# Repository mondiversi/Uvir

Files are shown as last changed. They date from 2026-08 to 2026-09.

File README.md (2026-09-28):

# Uvir

Android app for spectral irradiance acquisition and estimated biological effects.

## Status

Uvir is under active development. ESP32/AS7343 acquisition works over USB,
local Wi-Fi, Bluetooth and Internet through a standard MQTT broker over TLS. Optional AS7331
UVA/UVB/UVC acquisition is implemented in
energy-saving one-shot mode and awaits hardware validation and traceable
calibration when the UV board arrives.

## Android app

- Package: `me.mondiversi.uvir`
- Current version: `1.3.0` (sensor firmware `0.5.103`)
- Signed GitHub update checks at startup and from Info, verified APK downloads,
  and identity-checked USB sensor updates. The app is updated before the sensor.
  See [update and recovery documentation](docs/UPDATES.md).
- Multiple associated sensors can stay connected over Wi-Fi, Bluetooth or MQTT
  while one is selected for live display, settings and commands. Switching the
  selection keeps other sensors connected and continues saving their records.
  A single USB serial device can coexist with these wireless connections; USB
  hubs with multiple serial sensors are not yet supported. The no-sensor entry
  deliberately pauses all app connections without stopping hardware sessions.
- Spectral acquisitions, automatic acquisition, saved acquisitions, sharing and export, and estimated biological effects.
- Automatic acquisition can request unrestricted battery use and holds a partial wake lock while active, improving reliability when the screen is off. Force-closing the app can still stop the session.
- Firmware 0.5.95 makes the ESP32 the single authority for real-sensor
  averaging, automatic acquisitions and value alerts over USB, Wi-Fi and
  Bluetooth or Internet. While connected, completed automatic records are delivered from
  RAM and acknowledged by Android without routine flash writes. If the app
  connection drops, acquisitions, alerts and sensor errors are queued first in
  the sensor's 32 KiB FRAM, then on microSD when that queue fills,
  and synchronized after reconnection. Queued records are removed only after
  Android confirms that they are safely stored. Automatic-session and alert
  runtime state is checkpointed redundantly in FRAM, with the card as fallback.
  A DS3231 RTC on the
  shared I2C bus keeps UTC through a power loss, so valid sessions can resume
  autonomously without inventing records for the period in which the sensor
  was unpowered. The app corrects the RTC from the phone on every connection;
  invalid or uninitialized time still blocks every durable record.
- The in-app diagnostic performs six correlated probes and reports the complete
  hardware chain: processor and memory, AS7343/AS7331/DS3231/FRAM I²C state,
  FRAM and microSD read/write health, connection transports, LED and buzzer control
  paths, and the external-input GPIO. It does not create records or change
  settings and excludes every credential.
- Settings can be backed up from **Settings → Data and restore**: the app and
  each selected associated sensor produce separate password-encrypted
  `.uvirsettings` files. Multiple sensor backups can be imported together.
  A full database export is instead a password-protected AES-256 ZIP containing
  the SQLite database; it can be opened on a computer with a compatible ZIP
  program. The app can import that encrypted ZIP after checking the password,
  database integrity and schema version. Import replaces the local records and
  sensor profiles atomically; it does not change the physical sensor.
- Before an app authenticates, Internet, Bluetooth and local Wi-Fi now take
  part in the same 20-second recovery cycle. An invalid Internet broker or
  network therefore cannot leave the sensor permanently unreachable. Internet
  authentication also expires when the app stops communicating, so closing
  Android resumes the same recovery cycle even while the broker socket itself
  remains alive.
- Averaged automatic acquisitions are collected incrementally, so the ESP32
  continues to process connection, stop and diagnostic commands between raw
  samples instead of blocking for the complete averaging interval.
- Sensor parameters now group the RGB connection/activity LED, the separate
  blue pending-synchronization LED and an optional passive piezo buzzer. The
  buzzer uses GPIO 32,
  defaults to 10% volume, and confirms app connection, disconnection, activity
  start or stop, and every saved acquisition or alert without blocking sampling.

## Project structure

- `app/`: Android application.
- `firmware/esp32/UvirSensor/`: ESP32 firmware with separate AS7343 and optional AS7331 drivers plus the versioned Uvir USB/Wi-Fi/Bluetooth protocol.
- `relay/`: legacy experimental Uvir relay retained for reference; current Internet mode uses standard MQTT/TLS.
- `hardware/`: breadboard wiring, pinouts, schematics, bill of materials, and hardware test notes.

Third-party computers, phones and embedded USB hosts can control the sensor
without the Android app. See [USB serial integration](docs/USB_SERIAL_PROTOCOL.md)
for connection settings, commands, JSON responses, record acknowledgements and
safe offline synchronization.

## Remote Internet connection

Internet mode uses a standard MQTT 3.1.1 broker protected by TLS. Both the app
and the ESP32 establish outgoing connections, so no port needs to be opened on
the sensor's router. The broker address, TLS port and MQTT credentials are user
configuration: Uvir does not hard-code or depend on a particular provider.
Commands from the app use QoS 1; sensor events use non-blocking QoS 0, and
retained messages are disabled. Durable offline records remain protected by
Uvir's explicit `SYNC_ACK` and replay protocol. Uvir's sensor-specific
authentication remains active inside the encrypted MQTT channel.

See [ARCHITECTURE.md](ARCHITECTURE.md) for the current module boundaries and
the rules used for gradual, low-risk refactoring.

## First sensor test

Open `firmware/esp32/UvirSensor/UvirSensor.ino` in Arduino IDE, select
**ESP32 Dev Module**, choose **Huge APP (3MB No OTA/1MB SPIFFS)** under
**Tools → Partition Scheme**, and upload it to the ESP32. The Android app
recognizes the current CP210x USB serial bridge and asks for USB access when the
sensor is connected to the phone through a USB OTG data cable.

Disable **Settings → Debug → Mock data** before testing the real sensor. AS7343
VIS/NIR and optional AS7331 UV values remain datasheet-based estimates until
the assembled instrument is calibrated against a traceable reference.

## License

Licensed under the GNU General Public License v3.0. See [LICENSE](LICENSE).

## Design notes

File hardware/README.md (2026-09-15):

# Hardware

This directory is reserved for the physical design and assembly documentation
used by Uvir.

Planned contents:

- breadboard wiring diagrams;
- pin assignments and I2C addresses;
- power requirements and level-shifting notes;
- schematics and PCB revisions;
- bill of materials;
- assembly photos and sensor test notes.

The first carrier-board engineering draft is in
`pcb/uvir-carrier-r0`. It contains the verified logical schematic, preliminary
placement, BOM and fabrication profile. Gerbers remain intentionally blocked
until the exact physical modules have been measured.

Firmware source code belongs in `firmware/esp32/UvirSensor`. Keeping hardware
documents separate from firmware makes the repository easier to navigate as
the prototype evolves beyond a breadboard.

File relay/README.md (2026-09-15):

# Uvir Internet relay

The relay lets the Android app and an ESP32 sensor meet through the Internet
without exposing the sensor or opening a port on the home router. Both sides
create an outbound TLS connection and are paired using the sensor identity and
a key derived from its private access token. The normal authenticated Uvir
protocol then passes through unchanged.

## Requirements

- A small public server with a DNS name.
- A TLS certificate whose chain is rooted at Let's Encrypt ISRG Root X1.
- Node.js 20 or later. There are no third-party packages.

Set `UVIR_TLS_CERT` and `UVIR_TLS_KEY` to the full certificate-chain and private
key paths. Set `UVIR_RELAY_PORT` if the service does not listen on `443`, then
run `node uvir-relay.mjs`. Allow that inbound TCP port on the relay server only.
No port must be opened on the sensor's router.

The relay intentionally stores no measurements and logs no channel keys. It
only forwards bytes while both authenticated endpoints are online. Production
deployment should run it under a restricted service account, add connection
rate limits at the firewall, and restart it automatically after failure.

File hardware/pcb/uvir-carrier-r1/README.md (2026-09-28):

# Uvir Carrier R1 — EasyEDA Standard

## File to open in EasyEDA

`uvir-carrier-r1-easyeda-standard-schematic.json` is a **native EasyEDA Standard
electrical schematic**. The first version loaded the components but used only
short wire stubs with net names, so they appeared disconnected. This version
uses continuous wires and explicit junctions. It contains 13 symbols, 52 pins,
17 nets and 69 segments. The generator checks that every net is electrically
continuous in the drawing, rather than merely sharing a label.
The new version has not yet been reimported and visually checked in the EasyEDA
editor.

In EasyEDA **Standard** for PC:

1. Open `File > Open > EasyEDA...`.
2. Select `uvir-carrier-r1-easyeda-standard-schematic.json`.
3. Leave **Import File** selected and confirm.

Do not open the file by double-clicking it in Windows or choose Altium, Eagle
or KiCad. `uvir-carrier-r1-pin-netlist.json` is the reference logical pin map,
**not** a native EasyEDA document.

## Pin mapping and placement

The ESP32 symbol shows the `J2` (left row) and `J3` (right row) positions when
viewing the front of the board with USB at the bottom. These follow the
user-supplied `esp32_pin_ref.jpg` reference photo and agree with the 38-pin
ESP32-DevKitC pinout. The actual row spacing and pin pitch must still be measured
on the board before designing the sockets.

The **electrical schematic** arranges blocks to make the wiring readable; it
does not represent the physical PCB layout. Intended placement is recorded in
the logical pin map's `layout` section:

- **Front, bottom to top:** ESP32 with USB facing the bottom edge; horizontal
  AS7343 visible/NIR board above it; horizontal UV 5 Click board further up;
  buzzer, RGB LED and blue LED at the top. Side button on the left, slightly
  above the midpoint.
- **Back, bottom to top:** transverse RTC; clear ESP32 antenna area; FRAM above;
  microSD adapter at the top with the card accessible from the edge.
- **Approximate dimensions:** ESP32 25×52 mm; AS7343 22×13 mm;
  UV 5 Click 28.6×25.4 mm; RTC 37×22 mm; FRAM 20×15 mm;
  microSD 24×43 mm. These are not sufficient for fabrication.

The four I²C peripherals share GPIO21/SDA, GPIO22/SCL, 3.3 V and GND.
The microSD module uses GPIO13/18/19/23 for SPI, and only its VCC uses 5 V,
following the previously tested adapter with a regulator and level shifting.
Each LED has its own 330 Ω series resistor. Pressing the external button pulls
GPIO33 to GND: the chosen terminals are on opposite sides of the contact.

## Requirements before ordering the PCB

This document defines the connections; it is **not** a PCB layout. The module
symbols do not yet have physical footprints assigned. Before generating Gerbers:

- Measure pin 1, pin order, pitch and socket row spacing for every module,
  as well as LED/buzzer polarity and microSD orientation.
- Create/assign the footprints and place them on the actual front/back layout.
- Check the 3.3 V regulator budget, existing module I²C pull-ups, optical
  isolation and the antenna copper keepout.
- Check that RTC charging is disabled when using a CR2032.
- Run ERC, DRC and a human review before ordering.

`generate_easyeda_standard.py` regenerates the file from the logical pinout and
stops if a pin is missing or duplicated, a net is discontinuous, or the GPIO map
does not match `UvirHardwareConfig.h`.
The actual generator is `generate_connected_easyeda.py`; the original name
remains available for compatibility.

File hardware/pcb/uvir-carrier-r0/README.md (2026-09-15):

# Uvir Carrier PCB R0

Status: **engineering draft — not ready to order**.

This package fixes the electrical architecture and the intended physical
arrangement of the first Uvir carrier board. It deliberately does not contain
Gerber or drill production files yet: the exact physical ESP32 and GY-AS7343
module dimensions have not been verified. A correct logical pinout is not a
substitute for a mechanical footprint.

## Intended arrangement

From the USB edge toward the top edge:

1. ESP32 38-pin development board, USB connector accessible through the lower
   enclosure opening;
2. antenna keep-out, with no copper, ground plane, traces or components below
   the ESP32 antenna;
3. GY-AS7343 visible/NIR sensor, mounted horizontally and facing the front
   optical window;
4. SparkFun AS7331 UV sensor, mounted horizontally and facing its own front
   optical window;
5. opaque optical divider;
6. blue LED, common-cathode RGB LED and passive buzzer at the top edge. The LEDs
   use right-angle packages or light pipes so their output exits from the top
   face rather than shining toward the sensors. The buzzer may remain flat and
   use an acoustic duct to the top face.

Provisional carrier outline: **40 x 125 mm**, two copper layers, 1.6 mm FR-4.
This size is only a placement target and must be recalculated from the verified
footprints.

## Authoritative logical connections

- I2C SDA: GPIO 21;
- I2C SCL: GPIO 22;
- AS7343 address: `0x39`;
- AS7331 address: `0x74`;
- RGB red: GPIO 25 through 330 ohm;
- RGB green: GPIO 26 through 330 ohm;
- operation LED blue: GPIO 27 through 330 ohm;
- passive piezo buzzer: GPIO 32 and GND;
- sensor supply: 3.3 V after verification that each breakout contains the
  required regulator/level shifting.

## Files

- `uvir-carrier-r0-schematic.svg`: readable electrical schematic;
- `uvir-carrier-r0-layout.svg`: dimensioned placement drawing;
- `uvir-carrier-r0-pin-map.csv`: connector/net mapping;
- `uvir-carrier-r0-bom.csv`: preliminary bill of materials;
- `uvir-carrier-r0-cpl.csv`: preliminary placement list;
- `uvir-carrier-r0-board-outline.dxf`: provisional 40 x 125 mm outline;
- `fabrication-settings.md`: recommended fabrication settings and the exact
  checks required before Gerber generation.

## Measurements still required

Measure the physical parts with a caliper and record:

- ESP32 board width and length;
- center-to-center distance between its two 19-pin rows;
- location of pin 1, first/last pin and USB overhang;
- GY-AS7343 board width/length and exact order/position of its six pins;
- confirmation that the AS7331 is SEN-23517 Standard (25.4 x 25.4 mm), not the
  25.4 x 12.7 mm Mini version;
- buzzer diameter, height and lead spacing;
- LED package diameter and lead spacing;
- desired enclosure wall thickness and mounting-hole positions.

Only after these values are checked should the order bundle be generated:
Gerber X2/RS-274X, Excellon drill, BOM and component-position CSV. Those formats
are accepted by the main PCB fabrication services without tying the design to a
single provider.

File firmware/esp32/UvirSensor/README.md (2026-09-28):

# Uvir ESP32 sensor firmware

This sketch is the first hardware bridge between Uvir for Android and an
ESP32 Dev Module fitted with a GY-AS7343 spectral sensor and, optionally, an
AS7331 UV sensor. It streams visible, far-red, NIR, UVA, UVB and UVC bands over
USB serial, the local Wi-Fi network, Bluetooth Classic SPP, or an encrypted
Internet relay. Firmware keeps
working with UV values unavailable when the optional AS7331 is not installed.

## Settings authority and interrupted transfers

Firmware 0.5.102 reports `settings_updated_at_ms` in `HELLO`: UTC Unix
milliseconds of the last committed configuration change, persisted in NVS.
Receiving `TIME`, connecting, reading samples and running sessions do not refresh
this revision. Native serial configuration edits also advance it monotonically,
even if the runtime clock is unavailable or moves backwards.

Android keeps a separate revision/outbox for each hardware identity. Hardware
wins when its revision is equal or newer; otherwise Android resends its pending
configuration after authentication. Writes are queued durably before transfer
and are not acknowledged merely because a socket write succeeded. Pending
commands containing network credentials are excluded from Android cloud/device
backups; explicit encrypted settings exports include the desired settings.

`SETTINGS_APPLY <updated_at_ms> <hex_utf8_commands>` applies a bounded batch of
configuration commands separated by newlines. Its revision is committed only
after all commands succeed. Older/equal batches are ignored and answered with
`HELLO`. Interrupted/partially applied batches keep the previous revision and
can be retried. Radio reconnection is deferred until after commit/readback.
This is a recoverable configuration batch, not an atomic flash transaction.
The allowlist excludes acquisition, reset, session start/stop and other
operational commands. `ALERT_SETTINGS` synchronizes alert rules/timing without
changing an active session's identity, counters, cooldown or enabled state.

The outbox is invalidated when the association's access token changes (factory
reset), when that sensor is disassociated, or when the app's associations are
reset. Older firmware retains its previous sensor-authoritative readback behavior.

## Current wiring

| GY-AS7343 | ESP32 Dev Module |
|---|---|
| SDA | GPIO 21 |
| SCL | GPIO 22 |
| GND | GND |
| VIN/VCC | See the voltage warning below |
| I / INT | Not connected; optional active-low interrupt output |
| G / GPIO | Not connected; optional trigger/synchronization GPIO |

Optional SparkFun AS7331 / SEN-23517 on the same I2C bus:

| AS7331 | ESP32 Dev Module |
|---|---|
| SDA | GPIO 21 (shared with AS7343) |
| SCL | GPIO 22 (shared with AS7343) |
| GND | GND |
| 3V3 | 3.3 V |
| INT | Not connected |
| SYN | Not connected |

The sensors do not conflict: AS7343 uses address `0x39` and AS7331 uses
`0x74`. The AS7331 runs in command/one-shot mode and therefore does not need
its `INT` or `SYN` pins for Uvir.

HW-084 / DS3231 battery-backed real-time clock on the same I2C bus:

| RTC module | ESP32 Dev Module |
|---|---|
| SDA | GPIO 21 (shared I2C bus) |
| SCL | GPIO 22 (shared I2C bus) |
| VCC | 3.3 V |
| GND | GND |
| SQW / 32K | Not connected |

The DS3231 uses address `0x68`; the module's optional AT24C32 EEPROM commonly
uses `0x57` and is not used by Uvir. The backup cell powers only the clock when
main power is absent, so the module power LED going out is normal. If a CR2032
is fitted, the module's charging path must remain disabled. Uvir stores UTC in
the RTC and converts it for display in Android.

32 KiB MB85RC256V I²C FRAM on the shared bus:

| FRAM module | ESP32 Dev Module |
|---|---|
| SDA | GPIO 21 |
| SCL | GPIO 22 |
| VCC | 3.3 V |
| GND | GND |
| WP / A0 / A1 / A2 | Leave at the module defaults; do not drive high |

The tested board answers at `0x50`, independently of AS7343 (`0x39`), DS3231
(`0x68`) and optional AS7331 (`0x74`). FRAM keeps two checksummed copies of
the current activity state and up to 92 pending final records. Each record is
committed after a readback, then removed only after Android acknowledges it.
The remaining 4 KiB are reserved for future diagnostics. If FRAM is absent or
belongs to a different sensor, the microSD/LittleFS path remains available;
foreign FRAM contents are never silently erased.

Generic 6-pin microSD adapter with onboard level conversion (durable overflow
storage):

| microSD adapter | ESP32 Dev Module |
|---|---|
| CS | GPIO 13 |
| SCK | GPIO 18 |
| MOSI | GPIO 23 |
| MISO | GPIO 19 |
| VCC | 5 V / VIN |
| GND | GND |

The tested generic board uses an SN74HC125 level-conversion buffer and a 3.3 V
regulator, so its `VCC` input is powered from 5 V while all SPI signals remain
safe for the ESP32. Use a FAT32 card. The firmware binds a newly initialized
card to the ESP32 hardware identity, stores overflow acquisitions, alerts and
sensor errors under `/uvir`, and keeps two checksummed activity checkpoints as
a fallback when FRAM is unavailable. A card
belonging to another sensor is never silently adopted. If the card is missing,
the internal LittleFS partition remains a deliberately small emergency fallback.
Existing valid LittleFS records are migrated to the card without changing their
record IDs.

Capacity is calculated from the actual mounted card and the current binary
record size, while reserving 5% of the card (at least 16 MiB) for filesystem
headroom. The app reports total bytes, free bytes, total record capacity and
records still available in **Sensor information**. The diagnostic test performs
a temporary write/read/delete round trip without creating a measurement record.

Optional common-cathode RGB connection LED:

| RGB LED | ESP32 Dev Module |
|---|---|
| Common cathode | GND |
| Red anode | GPIO 25 through its own 330 Ω resistor |
| Green anode | GPIO 26 through its own 330 Ω resistor |

The RGB blue anode is not connected. GPIO 27 instead drives a separate blue
synchronization LED:

| Blue synchronization LED | ESP32 Dev Module |
|---|---|
| Anode | GPIO 27 through its own 330 Ω resistor |
| Cathode | GND |

Use one resistor per connected LED channel. A 470–1000 Ω value is also valid
when a lower physical brightness is preferred. The current firmware expects a
common-cathode RGB LED; a common-anode LED requires inverted output logic.

Optional low-current passive piezo buzzer:

| Passive buzzer | ESP32 Dev Module |
|---|---|
| Positive (`+`) | GPIO 32 |
| Negative (`-`) | GND |

The direct connection above is intended for a small passive piezo buzzer. An
active buzzer, magnetic transducer, or three-pin module may require a series
resistor or a transistor driver according to its electrical specifications.
The firmware generates the tones by PWM and starts at 10% volume.

External acquisition command (active low):

| Command contact | ESP32 Dev Module |
|---|---|
| Input | GPIO 33 (`INPUT_PULLUP`) |
| Return | GND |

A dry pushbutton or open-collector/open-drain output closes GPIO 33 to GND.
The input is enabled by default and its state is stored persistently by the
sensor; it can be disabled from **Settings > Management** in the Uvir app.
One short press records a standalone acquisition, or the next acquisition in
an external session. Three consecutive short presses start an external session;
the gesture itself does not create three records. A triple press is ignored
while any session is already active. Holding for two seconds stops the active
automatic or value-alert session. All gestures require a valid sensor clock;
otherwise the RGB LED flashes orange rapidly five times and the buzzer emits one
prolonged beep. Never apply 5 V directly to GPIO 33: use an optocoupler or a
properly designed level-shifting/protection stage for an industrial 5 V command.

The bare AS7343 operates at 1.8 V. Only connect the module to the ESP32 3.3 V
pin if the exact GY-AS7343 board includes a regulator and I2C level shifting.
Check the markings/schematic of the purchased module first. Never feed a bare
AS7343 directly from 3.3 V.

The `I` and `G` pads are not required by the current polling-based firmware and
should remain unconnected. A normal power bank exposes regulated USB power but
does not report its remaining charge to the ESP32. Battery percentage requires
a separate battery/fuel-gauge circuit (for example a dedicated I2C fuel-gauge
module); measuring the regulated 5 V USB output is not a useful state-of-charge
indicator because it stays nearly constant until the power bank shuts down.

## Upload with Arduino IDE

1. Open `UvirSensor.ino` from this folder.
2. Select the board **ESP32 Dev Module**.
3. Under **Tools → Partition Scheme**, select **Huge APP (3MB No OTA/1MB
   SPIFFS)**. The included `partitions.csv` mirrors this 3 MB application
   layout and gives the combined Wi-Fi/Bluetooth firmware enough space.
4. Select the ESP32 serial port.
5. Install **SparkFun AS7343 Arduino Library**, **SparkFun AS7331 Arduino
   Library**, and **SparkFun Toolkit** from the Library Manager if Arduino
   reports a missing library.
6. Upload the sketch.

The equivalent command-line build is:

```text
arduino-cli compile --fqbn esp32:esp32:esp32:PartitionScheme=huge_app firmware/esp32/UvirSensor
```

The repository copy is the working source: open and save this file directly
from this folder, so later changes stay under version control.

## USB protocol

For the standalone integration guide, including the recommended handshake,
measurement schema, automatic jobs and acknowledgement-safe offline recovery,
see [USB serial integration](../../../docs/USB_SERIAL_PROTOCOL.md).

The serial port uses 115200 baud, 8 data bits, no parity and one stop bit. Each
message is one JSON object followed by a newline. Protocol name:
`uvir-sensor-v1`.

Firmware image size is calculated once for the startup identity report and
cached in RAM until reboot. Periodic identity checks keep reporting current
settings and runtime information without re-verifying the flash image.
Wi-Fi JSON output uses a fixed 512-byte buffer to combine small formatting
writes. Every newline is sent immediately; reconnects discard any unfinished
output, and a failed send closes the socket rather than continuing a truncated
JSON frame. USB, Bluetooth and MQTT output are unchanged.

Commands accepted by the ESP32:

- `HELLO` or `PING`: report identity and capabilities;
- `DIAGNOSTIC <32-character hexadecimal request ID>` (full component report in
  firmware 0.5.92+): return one correlated `diagnostic` frame containing
  identity, firmware, processor, RAM/flash, connection state and the hardware
  map. Each probe checks the AS7343, optional AS7331 and DS3231 on I²C, performs
  a temporary microSD read/write round trip, reads the external input and
  reports the LED and buzzer control paths, pins and current configuration.
  The temporary microSD file is deleted immediately; settings, sessions and
  measurement records are never changed. LED and buzzer outputs are not
  actuated automatically because their final optical/acoustic result requires
  physical confirmation. Credentials are never included. Android sends six
  spaced probes over the selected transport, measures round-trip latency at
  receipt, and offers the localized report in a scrollable dialog and UTF-8 TXT
  export.
- `APP_CONNECT`: confirm that the authenticated transport is the source
  currently selected by Uvir, before synchronization and live streaming;
- `STREAM 150`: request one sample about every 150 ms;
- `SAMPLE`: acquire one sample;
- `SAMPLING_CONFIG 5 150 1`: keep five raw samples in ESP32 RAM, one every
  150 ms, discard the per-band minimum and maximum, and emit only the final
  averaged result;
- `LED_EVENT ACQUISITION`: briefly keeps the RGB activity indication visible
  after Android confirms a manual acquisition was saved. Automatic
  acquisitions are timed and signalled directly by the ESP32;
- `LED_EVENT ALERT`: compatibility/diagnostic command that shows the same RGB
  activity indication. During normal live use the ESP32 evaluates the
  configured rules on the same final averaged result sent to Android and
  signals the activity locally, without waiting for a return command from the
  phone;
- `LED_TEST`: when connected and idle, reproduces every status signal in legend
  order, then automatically restores the current real sensor state;
- `BUZZER_TEST`: when connected and idle, reproduces the connection,
  disconnection, activity-start, activity-stop and saved-record sounds, then
  returns to silence;
- `DEBUG_PERFORMANCE HAPPY_BIRTHDAY`, `DEBUG_PERFORMANCE INDIANA_JONES`,
  `DEBUG_PERFORMANCE JURASSIC_PARK`, or `DEBUG_PERFORMANCE STAR_WARS`: while
  connected and idle, starts the selected
  diagnostic theme locally on the ESP32. Notes and LED timing are stored in
  firmware, while the saved buzzer/LED switches, volume and brightness remain
  authoritative;
- `DEBUG_PERFORMANCE_STOP`: immediately cancels the current diagnostic theme
  and restores the real connection/activity and synchronization LED state;
- `DEBUG_FRAME 784 220 255 150 0`: legacy diagnostic command that plays one
  audiovisual frame without overriding saved buzzer or LED settings;
- `POWER_OFF`: when connected and idle, enters deep sleep. The sensor must then
  be restarted with EN/RESET or by cycling its power;
- `FACTORY_RESET`: restores sensor configuration and credentials to defaults,
  deletes every unsynchronized acquisition, alert and sensor error, and removes
  every Bluetooth Classic pairing stored by the ESP32. The Wi-Fi driver's own
  persistent network configuration is also restored and SSID/password readback
  is verified empty, even when resetting over USB or Bluetooth with Wi-Fi off.
  Reset cleanup starts STA without connecting to the old saved network and
  disables automatic reconnection. It acknowledges that reset has started before
  disconnecting the current peer, verifies both driver stores, and then enters
  deep sleep. A shared durable retry marker survives configuration erasure:
  interrupted/failed Bluetooth or Wi-Fi credential cleanup is retried
  at startup before any normal radio is enabled. Android may still retain its
  own old pairing entry, which must be forgotten/repaired on the phone. This
  does not change Uvir's app-only disassociation or revoke broker/router secrets;
- `STOP` or `SLEEP`: close the active app stream. The rolling measurement
  window continues in RAM so physical commands remain immediately usable;
  both spectral sensors still return to power-down between individual reads.
- `WIRELESS OFF`, `WIRELESS WIFI`, `WIRELESS BLUETOOTH`, or `WIRELESS INTERNET`: select and persist
  the only radio that should remain available after USB is disconnected.
- `RADIO WIFI ON/OFF` and `RADIO BLUETOOTH ON/OFF`: enable or disable each
  wireless transport persistently. An authenticated active radio may control
  the other one. USB is required only after both wireless transports have been
  disabled, because no wireless recovery channel then remains.
- `WIFI_CONFIG <SSID_HEX> <PASSWORD_HEX>`: store the existing WPA2/WPA3 Wi-Fi
  network credentials. It is accepted over USB or an already authenticated
  Wi-Fi/Bluetooth connection. USB remains the recovery path when no wireless
  connection is available.
- `INTERNET_CONFIG ON|OFF PRIMARY|SECONDARY <SSID_HEX_OR_-> <PASSWORD_HEX_OR_-> <RELAY_HOST_HEX_OR_-> <PORT>`:
  configure the encrypted remote relay. `PRIMARY` reuses the normal Wi-Fi
  credentials; `SECONDARY` stores a separate network, useful with a portable
  router. Both the sensor and app connect outward, so no sensor-router port is
  exposed.
- `WIFI_DISCONNECT`: disable and persistently turn off the Wi-Fi radio. This
  command is accepted only through an already authenticated Wi-Fi connection;
  Wi-Fi must then be re-enabled through USB.

The ESP32 stops sending frames automatically if it does not hear from the
Android host for 12 seconds. Measurement continues at the configured cadence
even without an active stream, keeping the latest averaged result ready in
RAM for autonomous and external commands. The sensor LED stays off and both
spectral devices return to power-down between reads. The default/recommended
interval is 150 ms; the safe range is 150–5000 ms. A capture that takes longer
still finishes before another sample is taken. Existing saved intervals are
preserved; the default applies to an unconfigured or factory-reset sensor.

## Wi-Fi and Bluetooth provisioning

Connect the ESP32 to Uvir by USB after flashing firmware 0.5.46 or later. The app learns
the device's unique ID, private authentication token, Bluetooth name and
pairing PIN. The identity is generated once and kept in ESP32 NVS and Android
private storage, so two otherwise identical sensors cannot be confused.

In Uvir, enter the name and password of the Wi-Fi network already used by the
phone. The first configuration may use USB; later changes may also be sent over
an already authenticated Wi-Fi or Bluetooth connection. The password is kept
in ESP32 NVS and Android private storage and is never returned over a wireless
connection.

Select Wi-Fi or Bluetooth from the source icon while USB is still connected.
After this first secure provisioning, Uvir can switch between the two radios
through whichever authenticated wireless connection is currently active.
The app waits for a `status` acknowledgement of the requested `wireless_mode`
before committing a connected handover. The new mode gets a fresh 20-second
window before normal fallback; repeated requests for an already exposed but
unauthenticated radio preserve and refresh that window too. A rejected request
leaves the previous source selected. Automatic jobs and alert sessions are not
stopped by a transport handover.
Selecting USB as the measurement source does not turn off the last wireless
radio, so disconnecting the data cable never strands the sensor offline. The
spectral devices remain powered down between individual conversions; use the
explicit Wi-Fi disconnect control when the radio itself must be disabled.
The ESP32 persists the chosen radio and keeps only that radio enabled. At
startup it tries the last successfully authenticated mode first. If Uvir does
not authenticate within 20 seconds, the sensor switches to the other configured
wireless transport and continues alternating until the app is found. Once Uvir
authenticates, that mode is saved and the fallback stops, so both radios are
never left active together. A transport disabled in Uvir settings is excluded
from this fallback; disabling both leaves the sensor in USB-only mode:

USB identity checks (`HELLO`/`PING`) do not interrupt fallback, which is useful
when the ESP32 is powered from a computer while the phone uses a wireless
source. Actual USB sampling (`SAMPLE`/`STREAM`) or an explicit radio command
stops the startup alternation.

- Wi-Fi joins the same existing router/access point as the phone, proves its
  identity through nonce-based HMAC discovery on UDP port `8732`, and serves
  the authenticated sensor protocol over TCP port `8733`;
- Bluetooth exposes the same unique name over Classic SPP and requires the
  generated six-digit pairing PIN;
- both wireless transports additionally require the private protocol token.

The periodic identity response also reports the current firmware, sensor and
board identity, uptime, effective sampling settings, available memory and radio
state. Wi-Fi signal is reported as RSSI in dBm. The current Bluetooth Classic
stack exposes a relative RSSI delta, which Uvir presents as link quality rather
than incorrectly labelling it as an absolute dBm value.

## Sampling and autonomous operation

The ESP32 is the single owner of real-sensor sampling. The configured raw
samples are kept only in RAM, the optional highest and lowest values are
removed independently for each band, and only the averaged result is sent to
Android. Android therefore does not average real frames a second time. The
same processing is used through USB, Wi-Fi and Bluetooth and while the phone
is absent. A transport-independent rolling window keeps the newest completed
average ready even when no app is connected. A physical external command
snapshots that value; only immediately after startup or a sampling/calibration
change does it wait for the replacement window to become valid. Each raw
sampling step performs one matching AS7331 one-shot
conversion; the UV sensor immediately returns to power-down before the next
step. Mock data remains generated and averaged by Android because no physical
sensor exists in that mode.

A logical acquisition tolerates up to three physical-read attempts for each
required sample. Retries are scheduled on later loop passes with a short delay,
so a transient I2C error does not discard an external command and does not block
connection or stop handling. This retry count is independent from the configured
number of raw samples used to calculate an averaged result. Once a final record
exists, live delivery remains pending until Android acknowledges durable storage;
offline writes are retried without replacing the record with a later reading.

When automatic acquisition or value alerts are active and the authenticated
phone connection disappears, the sensor continues from the last time and job
configuration received from Uvir. Completed acquisitions, alert events and
sensor errors are queued in FRAM first, with microSD (or emergency LittleFS)
as fallback or overflow. Raw intermediate samples are never persisted. At
reconnection the queue is transferred to Android. Each FRAM record is removed
after its individual acknowledgment; the filesystem queue is cleared after
its complete acknowledged transfer. The Android database deduplicates
repeated transfers by sensor ID and sensor record ID.

Autonomous offline recording can be disabled from **Sensor parameters**. This
pauses automatic acquisitions and alert evaluation only while the app is
disconnected; connected operation is unchanged and no final record is written
to flash unnecessarily. The same section offers an optional automatic shutdown,
disabled by default. Its idle timer lives in RAM and starts only when the app is
disconnected and no acquisition, alert monitoring, pending result or
synchronization is active. Waking from this low-power shutdown requires a
physical reset or a power cycle.

The active automatic-session and alert state is journaled in FRAM at meaningful
transitions and completed acquisitions, not on every raw sample. The RTC gives
the absolute time after power loss; recovery resumes valid work, closes expired
work and skips missed intervals without inventing measurements. If FRAM is
absent, the existing redundant microSD checkpoints remain the fallback.
Firmware 0.5.97 also journals alert-session start delay, end deadline and
completed-registration count; these limits remain effective without an app
connection and after a power cycle.

Firmware 0.5.98 makes acquisition and value-alert sessions mutually exclusive:
`OFFLINE_JOB` and `OFFLINE_EXTERNAL_JOB` are rejected while value alerts run,
and `ALERT_CONFIG ON` is rejected while automatic acquisition runs. `LED_TEST`
now includes the rapid orange, red and green event patterns as well as the
steady and slow-blinking states. If a journal written by older firmware
contains both activities, recovery keeps the automatic job and closes alert
monitoring without deleting its already stored records.

Firmware 0.5.100 rejects a short GPIO 33 acquisition during a normal automatic
or value-alert session with five orange flashes and one long tone. A short
press is accepted in an external-command session, or when no sensor job is
active. In the latter case, the app attaches the external record to an active
manual app session when one exists. `external_command` identifies the
individual record in live and synchronized messages. A long hold can still
stop the active sensor session.

The included custom partition reserves about 960 KiB for this queue. The
compact version-2 format supports up to 3200 final records while preserving
filesystem headroom. A legacy queue keeps its proven 1800-record ceiling until
it has been synchronized and cleared. The limit is shared by acquisitions,
alerts, and sensor errors. Existing records
are never overwritten: when the queue becomes full, autonomous recording is
stopped and the condition is reported to the app. After reconnection Android imports and
acknowledges every record before the ESP32 clears the queue; the recovery
summary also reports whether recording stopped because the memory was full.
The app uses the capacity and remaining-record values reported by the firmware
to show an offline-autonomy estimate if the connection is lost while automatic
acquisition or value alerts are active.

The RGB LED reports connection and activity: steady red means powered but not
connected to the app, flashing red means disconnected with an activity in
progress, flashing yellow means that an app connection is in progress, steady
green means connected, and flashing green means connected with an activity in
progress. The separate blue LED has one status meaning: steady blue indicates
that acquisitions, alerts, or errors remain in sensor memory waiting to be
synchronized. Three rapid red flashes indicate an acquisition or value alert
while disconnected; three rapid green flashes indicate the same while
connected. Five rapid orange flashes report that an explicit acquisition
cannot be saved, for example because date and time are unavailable or
value-alert monitoring is active. The RGB and blue indicators
work independently, so synchronization can show flashing green together with
steady blue.
LED use and brightness can be changed in Uvir under **Sensor parameters**.
The same section controls the optional status buzzer. It distinguishes app
connection, disconnection, activity start, activity stop and a saved record.
One prolonged tone reports the same missing-date rejection as the five rapid
orange flashes.
All sounds run in a dedicated task so they do not delay sampling or connectivity.

For Wi-Fi, leave the phone connected to the same local network. Uvir finds only
the previously associated sensor by matching its unique ID and secret token.
For Bluetooth, pair the displayed Uvir device from Android Bluetooth Settings.

## Irradiance values

Values are emitted in `uW/cm2` and explicitly marked `datasheet_estimate`. The
formula normalizes raw counts for actual gain and integration time, then uses
the AS7343 typical response measured at 155 mW/m² (15.5 µW/cm²), 1024× and
27.8 ms. The resulting values are channel-equivalent irradiance estimates,
not a traceable calibration of this physical module and not a full spectral
integration over each displayed color band.

They are suitable for end-to-end and relative-light tests. Absolute
measurements require per-device dark/scale calibration of the assembled optical
system against a calibrated source or spectroradiometer.

AS7331 UVA, UVB and UVC values use the SparkFun driver's datasheet conversion,
then the Uvir UV calibration factor. They also require comparison with a
traceable reference before being treated as absolute measurements.

Sensor drivers are isolated in `UvirVisibleSensor.h` and `UvirUvSensor.h`;
calibration coefficients remain in `Calibration.h`. This keeps acquisition
hardware separate from transport, session, alert and offline-storage logic.

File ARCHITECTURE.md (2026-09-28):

# Uvir architecture

## Signed updates

`UvirUpdateClient` owns signed-catalog verification and bounded HTTPS downloads.
`UvirUpdates` owns the process-scoped workflow, pending app-first plan and error
reporting. `UvirUpdateHost` presents ordered versions, progress and Android's
installation confirmation. `UvirEsp32RomUpdater` implements the classic ESP32 ROM
protocol behind a serial interface with mockable tests. `UvirUsbSensorManager`
leases a fresh exclusive USB connection only for an authenticated idle sensor
with synchronized records. `UvirFirmwareUpdateService` protects a flash from
screen sleep and activity navigation. `tools/ReleaseTool.java` creates the signed
public index offline; its signing key remains outside the repository.

See [update/recovery policy](docs/UPDATES.md) for compatibility and single-partition
limitations. The updater never needs a database migration or an app uninstall.

## Android

- `UvirAppRoot.kt` owns application lifecycle and cross-screen state.
- `UvirLiveScreen.kt` coordinates the live screen and its overlays.
- Dedicated screen and settings files contain the visual sections used by the
  two coordinators above.
- `UvirUsbSensorManager.kt` and `UvirWirelessSensorManager.kt` own transport
  lifecycles only.
- `UvirSensorProtocol.kt` is the single mapping from sensor JSON bands to the
  Android `SensorSample`, shared by USB, Wi-Fi, Bluetooth and offline records.
- `UvirOfflineSensorSync.kt` owns versioned commands and synchronized records.
- `UvirDatabase.kt` and the export files own persistence and interchange.

The two large coordinator files are intentionally reduced in small verified
steps. New protocol, database, export or reusable UI behavior should not be
added directly to them when it belongs to one of the dedicated modules.

Sensor profiles, connection credentials, settings and historical records are
kept per hardware identity. UvirMultiSensorRuntime retains an independent
authenticated Wi-Fi/Bluetooth/MQTT worker for each associated UID, alongside the
single physical USB-host transport. Selecting a sensor changes only the visible
live/settings context and command destination; other devices stay connected and
continue their autonomous sessions. The explicit no-sensor entry pauses all app
connections, not the jobs running on the hardware. Multiple USB serial devices
through a hub are not implemented.

UvirSensorEventHub tags every event with its authenticated transport's UID. One
retained UvirMultiSensorPersistence receiver stores all devices' records before
acknowledging them to their originating transport. UI collectors receive only
processed events for the selected UID. The shared database publishes foreground
and background revisions. Retransmitted records are deduplicated by UID + sensor
record ID; a recovered copy of a live alert attaches its hardware ID to the
original row rather than duplicating it. Sensor-originated session IDs are
mapped independently per UID. Credential and diagnostic readbacks cannot
activate another UI profile. Per-device status dots and named connection
messages continue to update while another sensor is selected. Global counter
reset is blocked while any known device has an active session.

The quiet connection foreground notification aggregates ephemeral states from
all retained transports. One sensor shows its saved name and state; multiple
sensors show connected/connecting/active/simulation counts, with named states
and the selected context in the expanded text. Simulation never counts as a
real connection or activity. An offline job is labelled as last known activity,
not counted as verified live activity. Changing UI context does not discard
another device's state. The payload is value-compared before updating the
service, so ordinary live sample changes do not repost an identical notification.
Automatic acquisition and alert notifications also identify their sensor by
app display name, falling back to hardware UID.

Session notes cannot be edited while their automatic/external/alert job is open,
or while their manual group is the remembered continuation target for its UID.
The four detail screens observe completion and per-sensor context changes; the
database also checks the lock inside each note-write transaction. Switching or
disconnecting a sensor does not finish its job or unlock its note. Finished
session notes, including deliberately empty notes, are authoritative over late
sensor records. This uses the existing session metadata without a schema change.

A new hardware identity requires explicit USB association or a valid encrypted
association backup; historical profiles and records remain after dissociation.
Every settings export is encrypted with a user-supplied password. App and sensor
settings selected together use the same password but remain separate files. A
sensor-settings backup also contains that sensor's hardware identity and
authentication token. Importing it restores the sensor as an offline selectable
profile without replacing the currently active sensor. Legacy unencrypted
backups remain import-compatible.
Factory reset clears the sensor-side token, so an older association backup can
no longer authenticate until a new physical USB association is completed.
`UvirSensorOperationalState.kt` clears only that active app context on
dissociation. Reopening the app retains it. Dissociation never finishes a
database session or stops an autonomous sensor job. On reassociation, sensor
readback restores an actually running job and visible counts follow persisted
Android records. If its schedule is no longer known, memory capacity is shown
without an invented time estimate based on another session's controls.

Sampling spacing defaults to 150 ms in Android preferences and all transports,
matching firmware defaults. A stored interval or sensor settings snapshot takes
precedence; changing the default does not migrate existing configurations.
Live UI refresh throttling and automatic/alert session timers are independent.

Chart axes share `UvirChartScale.kt`: linear scales use the largest valid visible
value plus 10% headroom, with no minimum of one in the selected display unit.
Live scales use only the rolling minute, animate in canonical units over 300 ms,
and keep new peaks visible throughout the transition. Saved/exported charts use
their represented records; grouped variant exports retain a common scale for
comparison. Axis labels adapt decimal precision or use compact scientific
notation. OL samples do not set the scale; percentage alert charts retain their
threshold-centered logarithmic reference. Neither stored data nor schema changes.

Automatic-acquisition draft cards reuse `SettingsSection` through the small
`UvirAutomaticAcquisitionSection` adapter. Checkbox and header taps share the
full-width clickable header, focus normalization and post-layout bring-into-view.
Automatic cards retain their neutral header/text colors when enabled; the checkbox
indicates the active option. Settings and Info keep their existing accent headers.
Expansion never starts or modifies a sensor job; a running conditional snapshot
remains immutable. Disabled choices and editors use the existing shared action,
radio and text-field styles rather than a second set of theme-specific controls.

## ESP32

- `UvirSensor.ino` coordinates protocol, connectivity, sessions, alerts and
  the main loop.
- `UvirVisibleSensor.h` owns AS7343 power, gain, integration and conversion.
- `UvirUvSensor.h` owns optional AS7331 one-shot acquisition and power-down.
- `Calibration.h` contains replaceable irradiance calibration coefficients.
- `UvirFram.h` owns bounded I²C access, the double activity-state journal and
  the non-destructive FRAM read/write diagnostic.
- `UvirOfflineStore.h` owns the acknowledged FRAM queue, microSD overflow queue,
  runtime-state migration and the bounded LittleFS emergency fallback.
- `UvirRtcClock.h` owns the DS3231 UTC clock, oscillator-validity check and
  phone-to-RTC synchronization without a third-party library.
- `UvirStatusLed.h` and `UvirStatusBuzzer.h` own non-blocking status feedback.

Sensor drivers return one complete band sample and do not know whether it will
be streamed, averaged, used by an alert or placed in the offline queue. This
keeps measurement behavior identical across USB, Wi-Fi and Bluetooth.

## Conditional automatic acquisition

Android stores the chosen mode and a per-sensor active snapshot in preferences.
Acquisition conditions have their own per-sensor phone-only rules, separate from
configured alerts. Starting a conditional acquisition copies enabled conditions;
subsequent edits never alter this copy. No database migration is required.

`UvirConditionalAcquisition.kt` and `UvirConditionalAcquisition.h` own matching,
validation and action decisions. The new atomic `OFFLINE_CONDITIONAL_JOB` command
requires firmware 0.5.75 for sample-level monitoring; ordinary `OFFLINE_JOB` is unchanged.
Readback of existing 0.5.73/0.5.74 snapshots remains supported. The ESP32 snapshot
lives only in RAM. Fresh HELLO/status frames report the waiting phase and actual
end deadline. Invalid/unavailable readings are unknown, never a satisfied NONE.

START monitors physical samples after the initial delay, then latches its first
matching sample and starts the duration clock and recording cadence. STOP monitors
between recordings and during averaging, without storing the triggering check.
ACQUIRE monitors until a match, preserves that first sample in the configured
averaging window, saves the measurement, then suspends its condition checks for
the full interval measured from completion. False/invalid checks never advance
the recording deadline, allocate an ID or count as a record. Live and alert reads
also feed the observer, avoiding separate blocking loops and missed crossings
while another measurement is collected. Alert rules and averaging stay separate.
Duration, maximum count and initial-delay guards always take priority. All monitor
transient samples remain in RAM; the durable job checkpoint is updated only at
meaningful state transitions and completed records, not on every sensor sample.
Conditional waiting/gating shows exact remaining capacity but no invented time
estimate, since future threshold crossings cannot be predicted. A triggered
START returns to the ordinary schedule estimate. After reboot the battery-backed
DS3231 restores the absolute clock before the durable checkpoint is reconciled.
Elapsed sessions close, missed intervals are skipped rather than fabricated,
and still-valid jobs resume with the same ID, counters, conditions and cadence.
If the RTC is absent or invalid, the existing no-date guard keeps the job paused.

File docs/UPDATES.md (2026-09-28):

# Uvir updates

Uvir checks the latest stable GitHub release once per process launch. In Info,
**Check for updates** runs the same check manually. A successful empty result is
silent automatically and shows a short message manually. Network, signature,
download, installer and USB failures go to the existing error log; they are not
reported as “no updates”. No update is installed without user action.

The availability dialog lists the app first, followed by associated sensors in
display-name order, with current and available versions. Sensor versions are the
last authenticated versions received from each sensor, not guesses. Unassociated
or never-identified hardware is not silently adopted by the updater.

## Authenticity and download

The public index is `releases/latest/download/uvir-update.json`. It is an envelope
containing a Base64 payload and an RSA SHA-256 signature. The app pins the public
release certificate; no private key or password is included in the repository.
Signed metadata includes versions, application ID, minimum app/Android versions,
firmware layout, download URLs, lengths and SHA-256 hashes. Files are downloaded
to private storage, bounded by the signed length, and verified before use. Only
this repository's HTTPS release URLs and GitHub's asset redirect hosts are allowed.
Equal or older versions are never offered as upgrades.

Android APKs must also have the expected package, version and signing certificate.
Android asks for installation permission/confirmation; this is not a silent
installer. Updating does not uninstall the app, clear its database or forget
sensor associations. A signed pending plan in non-backed-up storage survives
replacement of the app so firmware can be offered afterwards, including offline.

## Sensor USB update

Update the app first. Select the target sensor, connect it using USB OTG, finish
every session and synchronize all stored records. The updater checks the fresh
USB identity and idle/sync state, supported firmware (0.5.102 or newer), classic
ESP32 board and the 3 MiB application partition. Exclusive serial ownership
prevents the normal reader or heartbeat from interfering with the ROM protocol.
The ROM MAC identity, security configuration and actual partition-table digest
are checked again against signed release metadata before erase.
Secure boot, encrypted flash, custom flash pin wiring and other ESP32 families
are not supported by this updater.

Only the application at `0x10000`, up to `0x300000` bytes, is written. Bootloader,
partition table, NVS settings, SPIFFS, FRAM and microSD are not rewritten. An
independent foreground service and CPU wake lock protect the operation when the
display turns off or the app is backgrounded. Progress and actions are shared;
duplicate requests are disabled. Closing the progress popup is ignored while
busy. A flash MD5 verifies the transferred data; a new HELLO with the expected
identity/version is required before reporting success.

**Single-partition limitation:** there is no automatic firmware rollback. Never
remove USB power during a write. If interrupted, use the application-only recovery
command from the USB release archive on a computer. BOOT may need to be held to
enter the ROM loader. Do not erase the entire flash.

## Publishing

Write all public repository documentation, release titles, release notes and
future project-owned GitHub posts in English. This does not change the app's
localized interface strings. Reuse the English release-notes document when
publishing so the repository and the GitHub release stay consistent.

1. Increment the app version/code and sensor firmware version.
2. Run all tests, build the signed release APK and compile the ESP32 huge_app image.
3. Run `tools/ReleaseTool.java` with Java 17 or newer:

   `java tools/ReleaseTool.java ROOT OUTPUT FIRMWARE_BUILD 1.3.0 4 0.5.103`

4. Create a draft GitHub release tagged `v1.3.0`. Upload every generated asset:
   APK, application BIN, USB archive, signed index and SHA256SUMS.
5. Publish only after all uploads and validation succeed. The updater ignores
   drafts and prereleases through GitHub's latest-stable endpoint.
6. Download the public assets again and verify their sizes, signatures and hashes.

Keep `keystore.properties`, the keystore and all credentials outside source
control. Future key rotation needs an explicitly trusted migration, not simply
replacing the index certificate.

Physical testing of the AS7331 UV component remains pending until installation.

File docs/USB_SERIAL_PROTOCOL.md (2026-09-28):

# Uvir USB serial integration

Status: development documentation for protocol `uvir-sensor-v1`.

This document describes the USB interface currently implemented by the Uvir
ESP32 firmware. It is intended for computers, mobile devices and embedded
controllers that need to power and control the sensor without running the Uvir
Android application. It was verified against firmware `0.5.80`.

The protocol is usable now, but Uvir is still under active development. An
integrator should validate the `protocol` field and advertised capabilities
instead of depending only on a firmware version string.

## What an external controller can do

An external USB host can:

- read the sensor identity and capabilities;
- set the sensor clock;
- request individual samples or a continuous stream;
- configure sampling and calibration;
- start, monitor and stop automatic, conditional or external-command sessions;
- configure value-alert rules;
- receive live acquisition events;
- recover acquisitions, alerts and errors stored while no app was connected.

Only one host/transport owns an active app session at a time. USB, local Wi-Fi,
Bluetooth and Internet expose the same logical command protocol, but this guide
focuses on the trusted physical USB connection.

## Electrical and serial connection

The current development board exposes the ESP32 UART through a CP210x USB
bridge.

| Setting | Value |
|---|---|
| USB bridge currently recognized by Uvir | CP210x, VID `0x10C4`, PID `0xEA60` |
| Baud rate | `115200` |
| Data bits | `8` |
| Parity | none |
| Stop bits | `1` |
| Flow control | none |
| Command terminator | `LF`, `CR`, or `CRLF` |
| Response framing | one UTF-8 JSON object per line |
| Maximum command line handled by firmware | 512 characters |

The controlling device must act as a USB host. A USB power-only connection is
not sufficient. Some serial libraries toggle DTR/RTS when opening a port and
can reset an ESP32; after opening the port, wait for the startup `hello` frame
or send a fresh `HELLO` before continuing.

## Trust and authentication

USB is treated as a trusted physical transport and does not require `AUTH`.
Wireless transports additionally require the private token learned during the
trusted USB provisioning step.

The USB `hello` response can contain provisioning data that is deliberately
withheld from wireless responses. Treat it as sensitive: do not publish it,
write it to ordinary logs, or include it in diagnostic reports.

Physical USB access therefore grants control of the sensor. Products exposing
the port should apply their own physical-access policy.

### Switching the active wireless transport

An authenticated controller can send `WIRELESS WIFI`, `WIRELESS BLUETOOTH` or
`WIRELESS INTERNET` over its existing link. The sensor replies with a `status`
frame containing the requested `wireless_mode` before closing the old radio,
then enables the requested mode first. If the new link does not authenticate,
the normal 20-second fallback cycle through configured modes remains available.
The Android app checks this acknowledgement before saving its new selection;
a rejection, timeout or link loss does not count as confirmation. Without a
live link, selecting a source locally still uses normal reconnection. Selecting
USB does not send `WIRELESS OFF`, so wireless recovery is preserved.

## Framing and compatibility rules

Commands are ASCII text followed by a newline. Responses are newline-delimited
JSON. For example:

```text
PING\n
```

```json
{"type":"hello","protocol":"uvir-sensor-v1","device_id":"…","firmware":"0.5.80"}
```

An integration should:

- require `protocol == "uvir-sensor-v1"` for this version of the parser;
- use `type` to dispatch each incoming JSON object;
- ignore unknown JSON fields and unknown asynchronous frame types;
- never depend on JSON field order;
- preserve 64-bit IDs and Unix timestamps without converting them to
  floating-point numbers;
- wait for the appropriate status/error response instead of assuming that a
  write succeeded;
- reconnect and repeat `HELLO` after a serial reset or transport loss.

Errors have this common form:

```json
{"type":"error","protocol":"uvir-sensor-v1","code":"…","message":"…"}
```

`code` is the machine-readable value. `message` is intended for diagnostics
and may become more descriptive over time.

## Recommended connection sequence

1. Open the serial port at 115200 8N1.
2. Read the startup frames or send `HELLO`.
3. Verify `protocol`, `device_id`, sensor availability and the required
   capability fields.
4. Send `APP_CONNECT` if this host is going to act as the current live app
   session.
5. Send `TIME <unix_epoch_ms>` before recording anything.
6. Send `SYNC_BEGIN` and safely import any queued records.
7. Start `STREAM <interval_ms>` or issue other commands.
8. Send `STOP` before deliberately releasing the live connection.

Example:

```text
HELLO
APP_CONNECT
TIME 1789660800000
SYNC_BEGIN
STREAM 150
```

`TIME` accepts Unix epoch milliseconds from 2020 onward and synchronizes both
the powered runtime and the DS3231 battery-backed RTC. Android sends it on every
authenticated connection; a third-party host should do the same. After a power
loss the RTC supplies UTC autonomously. If it is absent, uninitialized or has
lost backup power, external-button and autonomous acquisitions remain rejected;
Uvir never creates intentionally undated records.

## Identity and status

### `HELLO` / `PING`

Returns a `hello` object containing identity, firmware, capabilities, current
sampling settings, time state, memory information, configured radios, offline
queue usage and current automatic/alert state.

Firmware 0.5.90 adds these storage fields:

- `storage_backend`: `micro_sd`, `internal_emergency`, or `none`;
- `storage_record_size_bytes`;
- `sd_available`, `sd_foreign`, and `sd_type`;
- `sd_total_bytes`, `sd_used_bytes`, and `sd_free_bytes`;
- `sd_record_capacity_total` and `sd_record_capacity_free`;
- `sd_invalid_records`, `sd_mount_errors`, and `sd_write_errors`.

Firmware 0.5.95 adds FRAM fields to `hello`: `fram_available`,
`fram_model`, `fram_i2c_address`, `fram_capacity_bytes`,
`fram_queue_available`, `fram_record_capacity`, and `fram_records_used`.
The `offline_*` counts include pending records in both FRAM and the
filesystem. A full FRAM queue spills new final records to microSD.

Record capacity reserves 5% of the card, with a minimum reserve of 16 MiB, and
therefore intentionally differs from raw free bytes divided by record size.

Time-related fields are `time_synced`, `current_time_ms`, `rtc_available`,
`rtc_valid`, `rtc_oscillator_stopped`, `rtc_read_ok`, `rtc_current_time_ms`,
`time_source`, `rtc_read_errors`, and `rtc_write_errors`.

Use capability fields such as `conditional_acquisition_supported` and
`external_command_supported` before presenting related controls.

### `APP_CONNECT`

Marks this transport as the active live app session and returns a `status`
frame. Taking ownership can stop live streaming on a previously active
transport; integrations must not try to control one sensor concurrently from
multiple hosts.

### `TIME <unix_epoch_ms>`

Sets the runtime clock and, when detected, the DS3231. The returned status
contains `"time_synced":true` and `rtc_updated`. Time remains valid through a
complete ESP32 power loss when the RTC backup cell and oscillator are valid.

### `DIAGNOSTIC <request_id>`

`request_id` must contain exactly 32 hexadecimal characters. Firmware 0.5.92+
returns a correlated `diagnostic` frame with identity, uptime, processor,
memory, storage, connection and session state. It also identifies every wired
component and reports the I²C acknowledgement and driver state for AS7343,
optional AS7331 and DS3231; microSD adapter/bus/pins and read/write result;
FRAM bus, queue and non-destructive read/write result (`fram_bus_ok`,
`fram_queue_available`, `fram_read_write_ok`); LED and buzzer control
paths/configuration; and the current GPIO33 external
input state. It never includes credentials or changes settings, sessions or
measurement records. It tests microSD via one bounded temporary
write/read/delete round trip (`sd_read_write_ok`) and FRAM by restoring the
original contents of a reserved diagnostic address. LEDs and buzzer are not
actuated by this command because
their final optical or acoustic result cannot be verified electrically.

## Reading measurements

### `STREAM <interval_ms>`

Starts transmission of the rolling measurements and makes the current
transport the active app session. Physical sampling already continues in the
background at the configured cadence, including while no app is connected.
The requested output interval is constrained to 150–5000 ms. The sensor
returns a status acknowledgement and then `sample` frames.

### `SAMPLE`

Returns the newest completed rolling average. Directly after startup or after
changing sampling/calibration settings, the command can produce no frame until
the configured RAM window has been filled. It does not start a second physical
sampling sequence.

### Sample frame

```json
{
  "type": "sample",
  "protocol": "uvir-sensor-v1",
  "seq": 42,
  "uptime_ms": 123456,
  "unit": "uW/cm2",
  "measurement_kind": "band_equivalent_irradiance",
  "calibration": "datasheet_estimate",
  "uv_available": true,
  "saturated": false,
  "gain": 256.0,
  "gain_ratio": 1.0,
  "integration_ms": 27.8,
  "samples_per_result": 5,
  "sample_spacing_ms": 150,
  "extremes_discarded": true,
  "bands": {
    "uvc": 0.0,
    "uvb": 0.0,
    "uva": 0.0,
    "violet": 0.0,
    "blue": 0.0,
    "green": 0.0,
    "yellow": 0.0,
    "orange": 0.0,
    "red": 0.0,
    "far_red": 0.0,
    "nir": 0.0
  }
}
```

The canonical transport unit is always `uW/cm2`; display-unit conversion is a
client responsibility. When `uv_available` is false, a client must not present
UV values as valid measurements. `saturated == true` means at least one value
was outside the usable range and should be represented as overload rather than
as a precise number.

### `STOP` / `SLEEP`

Stops live streaming for the active transport and powers down the spectral
sensors between operations. It does not erase stored records.

## Sampling and calibration configuration

### `SAMPLING_CONFIG <count> <spacing_ms> <discard>`

Example:

```text
SAMPLING_CONFIG 5 150 1
```

- `count`: 1–21 raw readings per final result;
- `spacing_ms`: 150–5000 ms;
- `discard`: `1` removes the per-band minimum and maximum when at least three
  readings are available, `0` keeps all readings.

### `CALIBRATION_CONFIG <visible_factor> <uv_factor>`

Both factors must be finite values from 0.1 to 10.0. Calibration is persistent.

### `SENSOR_CONFIG`

Current syntax:

```text
SENSOR_CONFIG <LED_ON|OFF> <brightness_0_100> <OFFLINE_ON|OFF> <BUZZER_ON|OFF> <volume_0_100> <AUTO_OFF_ON|OFF> <seconds> <EXTERNAL_ON|OFF>
```

These are persistent sensor settings. `EXTERNAL_ON|OFF` enables or disables the
GPIO 33 external-command input and defaults to `ON`, including after a factory
reset. Firmware 0.5.83 and later also accept the previous command without the
last token and leave the saved external-command setting unchanged. Configuration commands
may evolve as hardware capabilities are added; read back `HELLO` after changing
them.

## Automatic acquisition jobs

From firmware 0.5.98, automatic acquisition and value-alert monitoring are
mutually exclusive. `OFFLINE_JOB`, `OFFLINE_CONDITIONAL_JOB` and
`OFFLINE_EXTERNAL_JOB` return
`session_busy` while value alerts are active; stop them first with
`ALERT_CONFIG OFF ...`. Likewise, `ALERT_CONFIG ON ...` returns `session_busy`
while an automatic job is active; stop it first with `OFFLINE_STOP`.

All IDs and timestamps are unsigned decimal integers. A session note is stored
by the Uvir app rather than duplicated in every sensor record; `-` is the
reserved note token in the current wire format.

### Timed job

```text
OFFLINE_JOB <session_id> <next_at_ms> <interval_seconds> <end_at_ms> <maximum_count> <completed_count> <samples_per_acquisition> <sample_spacing_ms> <discard_0_or_1> -
```

Example:

```text
OFFLINE_JOB 1 1789660800000 5 1789660860000 12 0 5 150 1 -
```

`end_at_ms == 0` means no time deadline. `maximum_count == 0` means no count
limit. The sensor reports the accepted state through `automatic_status`.

### External-command job

```text
OFFLINE_EXTERNAL_JOB <session_id> <completed_count> <samples_per_acquisition> <sample_spacing_ms> <discard_0_or_1> -
```

In this mode a GPIO 33 active-low command is the only acquisition trigger.
Timing, maximum-count and conditional settings are intentionally ignored.
The trigger snapshots the newest compatible rolling average already held in
RAM. If that value is unavailable or stale, the sensor safely falls back to a
fresh configured acquisition.

GPIO 33 also supports autonomous control when no job was created by the app:

- one short closure stores a standalone external acquisition;
- three consecutive short closures start a sensor-originated external session,
  without storing the three gesture presses as acquisitions;
- one short closure during that external session stores its next sequenced
  acquisition;
- one short closure during a normal automatic session is rejected and cannot
  add a record to it;
- one short closure during a manual app session is delivered as an external
  acquisition within that manual session, marked as externally triggered;
- a short closure while value-alert monitoring is active is rejected with five
  orange RGB flashes and one prolonged buzzer tone;
- a closure held for at least two seconds stops the active automatic or
  value-alert session;
- a triple closure while an external session is already active is ignored;
  during a normal automatic or value-alert session it is rejected.

Sensor-originated sessions use a positive 64-bit remote token with bit 62 set.
Hosts must map the tuple `(device_id, remote session token)` to their own local
session identifier instead of displaying or adopting the token as a global ID.
The sensor reuses that token for live events and later offline synchronization.
All external gestures require a valid clock (from `TIME` or the RTC); without
it, no job or record is created and the sensor emits the same five-flash/long-beep
rejection signal.

### Conditional job

```text
OFFLINE_CONDITIONAL_JOB <base job fields> <START|STOP|ACQUIRE> <ANY|ALL|NONE> <duration_seconds> <rule_count> <metric> <ABOVE|BELOW> <threshold> [...]
```

Example:

```text
OFFLINE_CONDITIONAL_JOB 1 1789660800000 5 0 3 0 5 150 1 - START ANY 30 2 UV_TOTAL ABOVE 6.0 NIR_TOTAL BELOW 4.0
```

Supported metrics are:

```text
UV_TOTAL UVC UVB UVA HEV HEB VISIBLE_TOTAL VIOLET BLUE GREEN YELLOW
ORANGE RED NIR_TOTAL FAR_RED NIR BIO_DNA_UV BIO_UVA_PHOTOAGING
BIO_HEV_OXIDATIVE
```

The condition plan is a session-only snapshot held in RAM. It is independent
from the separately configured value-alert rules.

### `OFFLINE_STOP`

Stops the automatic acquisition job. Completion is confirmed by an
`automatic_status` frame where `job_active` is false.

## Live acquisition delivery

While a host owns an active app session, a completed automatic or external
acquisition is sent as an `acquisition_event`. Important fields include:

- `record_id`;
- `timestamp_ms`;
- `session_id` (`0` for a standalone external acquisition);
- `sequence`;
- `external_command` (`true` only when this specific record was triggered by
  GPIO 33, including records in external-command sessions);
- `completed_count` and `job_active`;
- the `bands` object.

After durably storing the record, reply with:

```text
ACQUISITION_ACK <record_id>
```

The sensor retries an unacknowledged live event. Never acknowledge a record
before it has been committed to durable storage. If the transport disappears
while an event is pending, the sensor moves that event to its offline queue.
Before creating that event, each required physical sample permits up to three
read attempts. These are recovery attempts for transient sensor/I2C failures,
not additional samples in the configured average.

## Value alerts

Replace the complete rule set atomically:

```text
ALERTS_CLEAR
ALERT_RULE <metric> <ABOVE|BELOW> <threshold>
ALERT_RULE <metric> <ABOVE|BELOW> <threshold>
ALERT_CONFIG ON <repeat_seconds> <session_id> <SAVE|NO_SAVE> <start_delay_seconds> <duration_seconds> <maximum_registrations>
```

Up to 24 distinct rules are accepted. Use `ALERT_CONFIG OFF ...` to stop alert
monitoring. Value alerts and automatic-acquisition conditions are different
features and do not overwrite one another.

The last three parameters were added in firmware 0.5.97. They may be omitted
by older clients and then default to zero (no delay, no duration limit, no
registration limit). Duration begins after the start delay. The sensor checks
the limits autonomously, including when Android is disconnected. A completed
alert counts toward the maximum only after it has been emitted or stored;
zero means unlimited. A power interruption does not restart either deadline.

`NO_SAVE` keeps threshold checking, LED and buzzer feedback active without
creating alert records on the sensor. Connected `alert_event` frames still
report the occurrence with `"recorded":false`; clients must not add these
events to their databases. `SAVE` is the default when the final token is
omitted by an older client. The mode survives power loss with the alert
configuration. A no-save session uses session ID `0`.

## Offline synchronization

Offline synchronization is an acknowledgement-driven sequence. The queue can
contain acquisitions, alerts and sensor errors.

1. Host sends `SYNC_BEGIN`.
2. Sensor sends `sync_start` with counts and `storage_was_full`.
3. Sensor sends one `offline_record`.
4. Host validates and durably stores or deduplicates it.
5. Host sends `SYNC_ACK <record_id>`.
6. Sensor removes that acknowledged record and sends the next one.
7. The sequence ends with `sync_complete`.

If a record cannot be stored, do not acknowledge it. Disconnect or retry later;
the sensor preserves unacknowledged data. The Android database deduplicates by
sensor identity plus sensor record ID.

An acquisition `offline_record` contains `session_id`, `sequence` and `bands`.
An alert contains `session_id` and encoded `details`. An error contains `code`
and `message`.

## Using another controller before Uvir synchronizes

Two operating models are valid, but they must not be mixed accidentally.

### Controller owns the live records

Send `APP_CONNECT`, receive `acquisition_event` frames, store each record and
send `ACQUISITION_ACK`. Those acknowledged records are owned by the controller
and will not later appear in the sensor's offline queue.

### Sensor keeps records for later Uvir recovery

Set `TIME`, configure the job, then release the live app session with `STOP`.
Leave autonomous recording enabled. The ESP32 records final acquisitions in
its own offline queue, and Uvir can later import them through `SYNC_BEGIN`.

With firmware 0.5.95, FRAM is the first queue for up to 92 pending final
records; microSD is the overflow and fallback queue. Current automatic-job and
alert state is stored in alternating checksummed FRAM checkpoints after meaningful
changes and completed records (on microSD when FRAM is unavailable at startup).
Following a complete power loss, a valid DS3231
clock lets the firmware reconcile the restored job autonomously: expired jobs
close, missed intervals are skipped without synthetic catch-up measurements,
and a still-valid job keeps its session ID, counters, schedule and conditions.
Without a valid RTC the job remains paused until a host sends `TIME`.

This second model is appropriate when another apparatus merely powers,
configures or triggers the sensor and the Android app remains the long-term
record owner.

Plain `SAMPLE`/`STREAM` results are live measurements, not database records.
They are not automatically imported into Uvir later.

## Destructive and power commands

- `POWER_OFF` enters deep sleep when no acquisition or alert activity is
  running. Physical reset or a power cycle is required to wake the sensor.
- `FACTORY_RESET` removes sensor settings, credentials, Bluetooth bonds and
  every unsynchronized record, then powers the sensor down.

Do not expose either command through an unattended integration without an
explicit confirmation and suitable authorization.

## Minimal host pseudocode

```text
open serial 115200 8N1
send "HELLO\n"
hello = wait for JSON type "hello"
assert hello.protocol == "uvir-sensor-v1"

send "APP_CONNECT\n"
wait for status.app_connected == true
send "TIME <current Unix epoch milliseconds>\n"

send "SYNC_BEGIN\n"
for each offline_record:
    commit record using (device_id, record_id) as the durable identity
    send "SYNC_ACK <record_id>\n"
wait for sync_complete

send "STREAM 150\n"
consume sample frames
...
send "STOP\n"
close serial
```

## Source of truth

Until the public protocol is frozen, implementation remains authoritative:

- firmware command parser: `firmware/esp32/UvirSensor/UvirSensor.ino`;
- conditional grammar: `firmware/esp32/UvirSensor/UvirConditionalAcquisition.h`;
- Android USB client: `app/src/main/java/me/mondiversi/uvir/UvirUsbSensorManager.kt`;
- Android command builders: `app/src/main/java/me/mondiversi/uvir/UvirOfflineSensorSync.kt`.

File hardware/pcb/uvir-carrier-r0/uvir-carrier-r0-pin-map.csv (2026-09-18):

Reference | Pin | Net | Destination | Status | Notes
ESP32-L | 1 | 3V3 | Sensor supply and decoupling | verified | Top pin with USB facing down
ESP32-L | 7 | GPIO32 | BZ1 positive | verified | Low-current passive piezo only
ESP32-L | 8 | GPIO33 | EXT_CMD | verified-logical | Active-low dry contact to GND; protect/level-shift any 5 V input
ESP32-L | 9 | GPIO25 | R1 to RGB red anode | verified | 330 ohm
ESP32-L | 10 | GPIO26 | R2 to RGB green anode | verified | 330 ohm
ESP32-L | 11 | GPIO27 | R3 to blue LED anode | verified | 330 ohm
ESP32-L | 14 | GND | Ground plane | verified
ESP32-L | 19 | 5V | Reserved | verified | Do not join to a second power source
ESP32-R | 1 | GND | Ground plane | verified | Top pin with USB facing down
ESP32-R | 3 | GPIO22 | I2C_SCL | verified | Shared by AS7343 and AS7331
ESP32-R | 6 | GPIO21 | I2C_SDA | verified | Shared by AS7343 and AS7331
ESP32-R | 7 | GND | Ground plane | verified
AS7343 | TBD | 3V3 | ESP32 3V3 | mechanical-check | Exact module pin order must be measured
AS7343 | TBD | GND | Ground plane | mechanical-check | Exact module pin order must be measured
AS7343 | TBD | SDA | I2C_SDA | mechanical-check | Address 0x39
AS7343 | TBD | SCL | I2C_SCL | mechanical-check | Address 0x39
AS7343 | TBD | INT | NC | verified-logical | Leave unconnected
AS7343 | TBD | GPIO | NC | verified-logical | Leave unconnected
AS7331 | TBD | 3V3 | ESP32 3V3 | mechanical-check | SEN-23517 PTH order must be checked
AS7331 | TBD | GND | Ground plane | mechanical-check | SEN-23517 PTH order must be checked
AS7331 | TBD | SDA | I2C_SDA | mechanical-check | Address 0x74
AS7331 | TBD | SCL | I2C_SCL | mechanical-check | Address 0x74
AS7331 | TBD | INT | NC | verified-logical | Leave unconnected
AS7331 | TBD | SYN | NC | verified-logical | Leave unconnected
RGB | RED | GPIO25 via R1 | ESP32 | verified | Common-cathode LED
RGB | GREEN | GPIO26 via R2 | ESP32 | verified | Common-cathode LED
RGB | COMMON | GND | Ground plane | verified
RGB | BLUE | NC | None | verified | Leave unconnected
BLUE_LED | ANODE | GPIO27 via R3 | ESP32 | verified
BLUE_LED | CATHODE | GND | Ground plane | verified
BZ1 | POSITIVE | GPIO32 | ESP32 | verified | Direct connection only for low-current passive piezo
BZ1 | NEGATIVE | GND | Ground plane | verified

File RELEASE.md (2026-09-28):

# Uvir distribution

## Application identity

- Display name: `Uvir`
- Application ID: `me.mondiversi.uvir`
- Namespace: `me.mondiversi.uvir`
- Current version: `1.3.0` (`versionCode` 4)
- Sensor firmware: `0.5.103`

## Building the APK

Double-click `CREA_APK_RELEASE.bat`.

When the build finishes, the signed APK ready for distribution is available at:

```text
dist\Uvir-1.3.0-release.apk
```

The same directory also contains `Uvir-1.3.0-release.apk.sha256`, which can be
used to verify that a download has not been modified or corrupted.

The APK can be attached to a GitHub release or distributed from a website.
Make the corresponding source available in accordance with the project's
[GPL-3.0 license](LICENSE).

For a complete release (APK, USB firmware, signed index and checksums), follow
[docs/UPDATES.md](docs/UPDATES.md). Publish the release only after all files have
been uploaded. Physical validation of the AS7331 UV sensor remains pending until
the component is available.

## Signing and updates

The private signing key is stored outside the project at:

```text
C:\Users\otta8\Documents\UvirSigning\uvir-release.jks
```

The local configuration containing the signing credentials is in
`keystore.properties`. Keep both files in a secure, private backup. Never upload
them to GitHub, share them or include them in public archives.

The exported public certificate is available at:

```text
C:\Users\otta8\Documents\UvirSigning\uvir-release-certificate.pem
```

The public certificate may be shared; the private `.jks` key must not be shared.

To publish an update:

1. Increment `versionCode` in `app/build.gradle.kts`.
2. Update `versionName`.
3. Always use the same release signing key.
4. Rebuild the APK with `CREA_APK_RELEASE.bat`.

On the development computer, the `debug` variant launched from Android Studio
also uses this key when `keystore.properties` is present. This lets **Run** and
**Debug** update an existing installation without certificate conflicts. On other
computers without this private configuration, Gradle automatically falls back to
the normal local debug key.

If the release key or its password is lost, future APKs will not be able to
update an existing installation.

## Public content language

Use English for repository documentation, GitHub release titles and release
notes, build-tool messages and future project-owned GitHub posts. The Android
app remains multilingual; its localized interface strings are not subject to
this documentation rule.

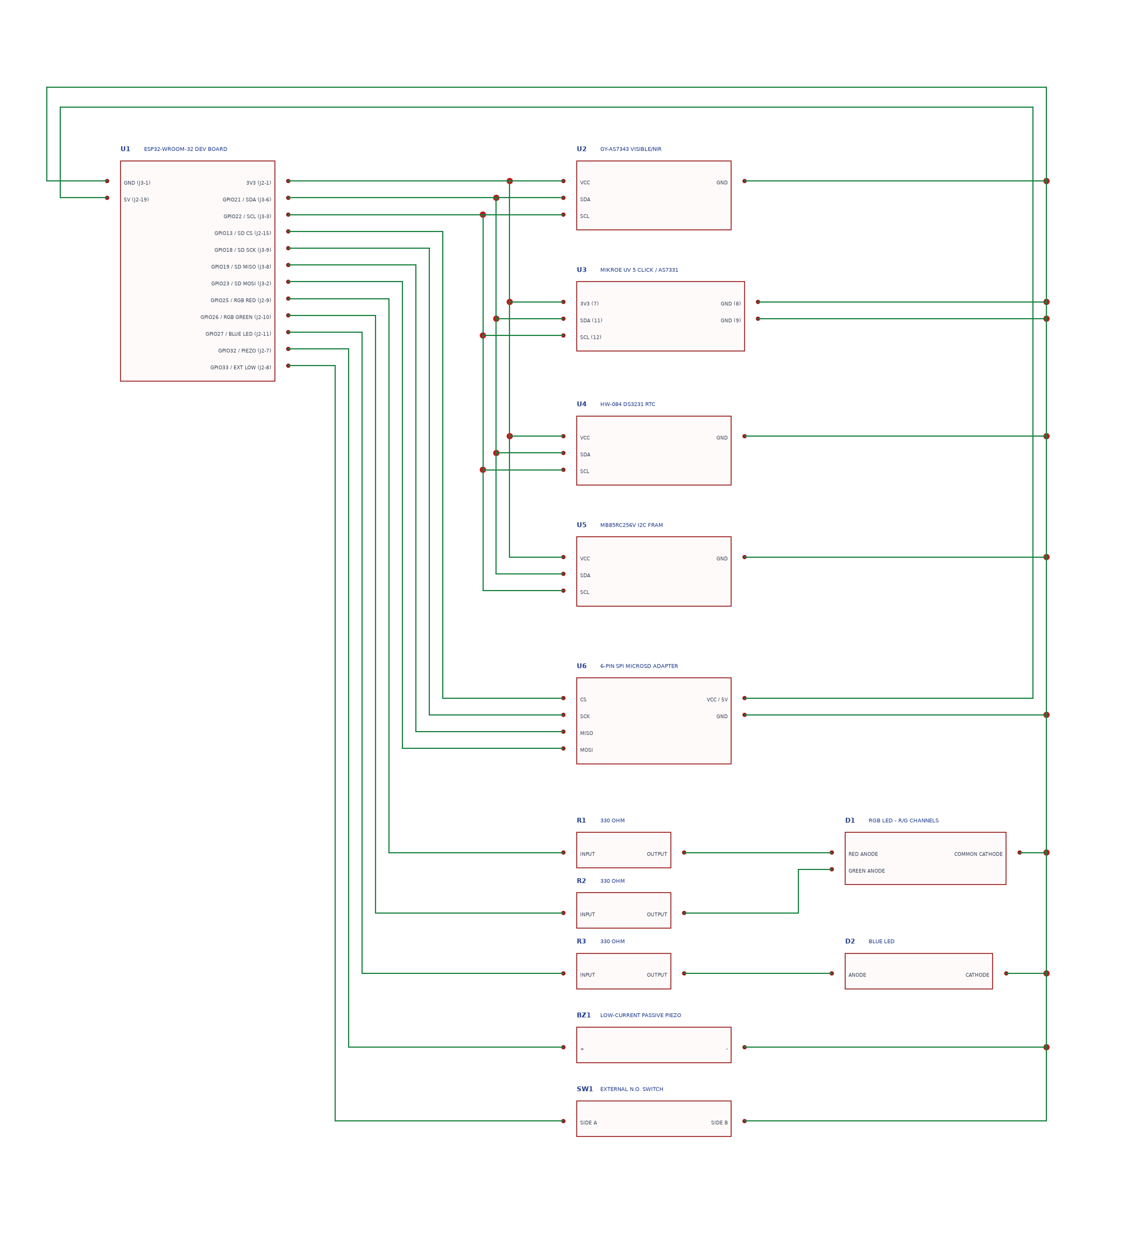
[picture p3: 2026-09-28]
hardware/pcb/uvir-carrier-r1/uvir-carrier-r1-schematic-preview.png

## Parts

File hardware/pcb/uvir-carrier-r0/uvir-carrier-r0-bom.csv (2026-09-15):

Designator | Quantity | Description | Value_or_part | Footprint | Assembly | Verification
U1 | 1 | ESP32 development board 38 pin | ESP-WROOM-32 Dev Module | Two rows 1x19 P2.54 mm | Hand fitted | MEASURE EXACT BOARD
U2 | 1 | Visible and NIR spectral sensor module | GY-AS7343 | Module footprint TBD | Hand fitted | MEASURE MODULE AND PIN ORDER
U3 | 1 | UV spectral sensor breakout | SparkFun SEN-23517 AS7331 | 25.4 x 25.4 mm module footprint | Hand fitted | CONFIRM STANDARD VERSION
D1 | 1 | Right-angle common-cathode RGB LED | Red and green channels used | Package TBD | Hand fitted | MEASURE PACKAGE
D2 | 1 | Right-angle blue operation LED | Blue | Package TBD | Hand fitted | MEASURE PACKAGE
R1 R2 R3 | 3 | LED series resistor | 330 ohm 1 percent | 0805 | SMD | Verified electrical value
BZ1 | 1 | Low-current passive piezo buzzer | 3.3 V PWM compatible | Diameter and pitch TBD | Hand fitted | MEASURE AND VERIFY CURRENT
C1 C2 | 2 | Local ceramic bypass capacitor | 100 nF 16 V X7R | 0805 | SMD | Recommended
C3 | 1 | Bulk ceramic capacitor | 10 uF 10 V X7R | 0805 | SMD | Recommended
R4 R5 | 2 | Optional I2C pull-up | DNP 4.7 kohm | 0805 | SMD | DNP because sensor modules normally include pull-ups
J1 J2 | 2 | ESP32 low-profile socket | 1x19 P2.54 mm | PinSocket 1x19 vertical | Hand fitted | ROW SPACING TBD
J3 | 1 | AS7343 removable header | 1x6 P2.54 mm | PinSocket 1x6 vertical | Hand fitted | PIN ORDER TBD
J4 | 1 | AS7331 removable header | 1x6 P2.54 mm | PinSocket 1x6 vertical | Hand fitted | PIN ORDER TBD

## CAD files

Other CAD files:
hardware/pcb/uvir-carrier-r0/uvir-carrier-r0-board-outline.dxf

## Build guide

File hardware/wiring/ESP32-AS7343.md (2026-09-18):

# ESP32 Dev Module + GY-AS7343

## Controller reference

The prototype currently reports an `ESP32-D0WD-V3` revision 3.1 inside an
ESP-WROOM-32 development module. Use the common 38-pin ESP-WROOM-32 Dev Module
diagram supplied with the project as the **logical GPIO reference**. It agrees
with the GPIO assignments below, but it is not an authoritative mechanical PCB
footprint: before laying out a carrier PCB, verify the exact board width, header
spacing, pin order, and USB overhang on the physical module.

The firmware's authoritative pin and I2C map is kept in
`firmware/esp32/UvirSensor/UvirHardwareConfig.h` so wiring documentation and
future PCB schematics can be checked against one source.

Initial Uvir prototype wiring:

| Signal | ESP32 | AS7343 module |
|---|---:|---:|
| I2C data | GPIO 21 | SDA |
| I2C clock | GPIO 22 | SCL |
| Ground | GND | GND |
| Supply | verify module first | VIN/VCC |

Optional status outputs:

| Peripheral | ESP32 | Connection |
|---|---:|---|
| RGB LED red | GPIO 25 | Through its own 330 Ω resistor |
| RGB LED green | GPIO 26 | Through its own 330 Ω resistor |
| RGB LED common cathode | GND | Direct |
| Separate blue LED anode | GPIO 27 | Through its own 330 Ω resistor |
| Separate blue LED cathode | GND | Direct |
| Passive piezo buzzer `+` | GPIO 32 | Direct for a low-current passive piezo |
| Passive piezo buzzer `-` | GND | Direct |
| External command input | GPIO 33 | Dry contact to GND; internal pull-up |

Leave the blue anode of the RGB LED disconnected. The RGB red and green
channels show connection state; the separate blue LED shows active operations
and newly recorded acquisitions or alerts.

Check the electrical specifications before using an active buzzer, magnetic
transducer, or three-pin module; it may need a transistor driver.

GPIO 33 is a 3.3 V input. A button can connect it directly to GND, but a 5 V
logic signal requires an optocoupler or a suitable protected level shifter.
The external-command input is enabled by default and can be disabled from the
sensor Management settings in the app; that choice is stored persistently on
the sensor.
One short closure records, three consecutive short closures start an external
session, and a closure held for two seconds stops the active session. Short and
triple closures are ignored while a non-external session is active. A dry
contact, open-drain/open-collector output or correctly isolated industrial
controller may use the same input semantics.

The AS7343 silicon uses a 1.8 V supply and 1.8 V I/O. Many breakout boards add
a regulator and level shifting, but the exact GY-AS7343 module must be checked
before it is connected to 3.3 V. A product photo alone is not enough to prove
the electrical design.

For the first Android test the ESP32 is connected to the phone through a USB
OTG data adapter/cable. Its CP210x USB-to-UART bridge identifies itself as
VID `10C4`, PID `EA60`.

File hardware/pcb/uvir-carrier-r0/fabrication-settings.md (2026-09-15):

# Fabrication settings — Uvir Carrier R0

These settings are suitable for a low-cost first prototype after all footprints
have been verified.

- Layers: 2
- Material: FR-4
- Finished thickness: 1.6 mm
- Copper: 1 oz outer layers
- Solder mask: green or black
- Silkscreen: white
- Surface finish: lead-free HASL; ENIG is optional, not required for the carrier
- Minimum signal track: 0.25 mm
- 3.3 V and GND tracks: 0.50 mm or wider
- Via: 0.60 mm pad / 0.30 mm drill or the fabricator's standard
- Copper-to-edge clearance: at least 0.30 mm
- Ground pour: both layers, except the ESP32 antenna keep-out
- Controlled impedance: not required
- Castellations, blind/buried vias and edge plating: not required
- Panelization: fabricator standard

## Required production bundle

The final ZIP should contain:

- top and bottom copper Gerbers;
- top and bottom solder-mask Gerbers;
- top and bottom silkscreen Gerbers;
- board-outline Gerber;
- plated and non-plated Excellon drill files;
- Gerber job file when supported;
- BOM CSV and component-position CSV only if assembly is requested.

## Do not order R0 yet

The current DXF, placement CSV and drawings express the intended architecture,
but U1/U2 header positions and several mechanical component footprints remain
unverified. Generating Gerbers before measuring them would create a board whose
electrical netlist could be correct while the real modules do not physically fit.

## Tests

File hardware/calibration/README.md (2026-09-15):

# Calibration

The first AS7343 firmware produces provisional irradiance estimates so the
complete acquisition path can be tested before laboratory calibration.

Before values are considered absolute measurements:

1. record dark readings for every channel with the sensor optically covered;
2. expose the assembled sensor to traceable reference sources across the
   supported spectrum;
3. determine per-channel scale factors for the final enclosure and diffuser;
4. update `firmware/esp32/UvirSensor/Calibration.h`;
5. document the reference instrument, geometry, temperature and uncertainty.

UVA, UVB and UVC calibration will be added when the AS7331 sensor is available.

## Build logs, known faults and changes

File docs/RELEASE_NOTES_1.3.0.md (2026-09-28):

# Uvir 1.3.0 — sensor firmware 0.5.103

Consolidation of the Android/ESP32 platform and the first GitHub update system
with a signed index and verified downloads.

## Highlights

- Multi-sensor management: independent connections and recordings, with one
  sensor selected for display and commands.
- Acquisitions, alerts, autonomous sessions, external commands and session variants.
- Offline recording in FRAM/microSD and state recovery with the DS3231 RTC.
- CSV/TXT/PNG exports, encrypted backups and extended diagnostics.
- Refined interface, localization, accessibility and sensor selection.
- Automatic and manual update checks, an ordered version list, verified downloads,
  app updates before sensor updates, and failure logging.
- USB firmware updates with identity, idle-state and memory-layout checks.
  Settings and data are preserved.

## Files

- `Uvir-1.3.0.apk`: signed Android app (Android 8 or later).
- `UvirSensor-0.5.103-esp32.bin`: ESP32 application image only.
- `UvirSensor-0.5.103-usb.zip`: firmware and USB instructions for updates,
  recovery and first installation.
- `uvir-update.json`: signed index for in-app update checks.
- `SHA256SUMS.txt`: checksums of the published files.

## Validation and limitations

Android and firmware builds completed; JVM tests, firmware-logic tests and phone
checks performed. The physical sensor was updated from a computer over USB,
with its identity, settings, credentials and record counts checked before and
after the update, without creating artificial acquisitions.

The AS7331 UV sensor is not yet available: physical validation and calibration
remain pending. Firmware uploads directly from the app over USB OTG still
require a physical test of that connection; the protocol, safety checks and
release files are tested separately.

**Do not disconnect power during a firmware upload.** The ESP32 uses a single
application partition: automatic rollback is not available. For recovery, use
the USB procedure included in the archive without erasing the entire flash.

Documentation: [updates and recovery](UPDATES.md),
[serial interface](USB_SERIAL_PROTOCOL.md).

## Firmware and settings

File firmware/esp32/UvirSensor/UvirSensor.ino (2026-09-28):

#include <Arduino.h>
#include <ArduinoMqttClient.h>
#include <BluetoothSerial.h>
#include <Preferences.h>
#include <WiFi.h>
#include <WiFiClientSecure.h>
#include <WiFiUdp.h>
#include <Wire.h>
#include <atomic>
#include <esp_bt_main.h>
#include <esp_gap_bt_api.h>
#include <esp_ota_ops.h>
#include <esp_sleep.h>
#include <esp_wifi.h>
#include <mbedtls/md.h>
#include <nvs.h>

#include "UvirBluetoothBondReset.h"
#include "UvirHardwareConfig.h"
#include "UvirDebugPerformance.h"
#include "UvirPublicCaBundle.h"
#include "UvirOfflineStore.h"
#include "UvirFram.h"
#include "UvirRtcClock.h"
#include "UvirConditionalAcquisition.h"
#include "UvirAcquisitionRetry.h"
#include "UvirExternalCommandPolicy.h"
#include "UvirStatusBuzzer.h"
#include "UvirStatusLed.h"
#include "UvirUvSensor.h"
#include "UvirVisibleSensor.h"
#include "UvirWifiOutput.h"
#include "UvirWifiCredentialReset.h"

namespace {

constexpr char kProtocol[] = "uvir-sensor-v1";
constexpr char kFirmwareVersion[] = "0.5.103";
constexpr uint8_t kSensorSettingsSchemaVersion = 2;
constexpr uint32_t kHostTimeoutMs = 12000;
constexpr uint32_t kMinimumStreamIntervalMs = 150;
constexpr uint32_t kMaximumStreamIntervalMs = 5000;
constexpr uint32_t kDefaultStreamIntervalMs = 150;
constexpr uint16_t kWifiPort = 8733;
constexpr uint16_t kWifiDiscoveryPort = 8732;
constexpr uint32_t kWifiReconnectIntervalMs = 10000;
constexpr uint32_t kInternetReconnectIntervalMs = 10000;
constexpr uint32_t kInternetConnectTimeoutMs = 8000;
constexpr uint32_t kWirelessAuthenticationTimeoutMs = 5000;
constexpr uint32_t kWirelessFallbackIntervalMs = 20000;
constexpr uint32_t kSignalUpdateIntervalMs = 2000;
constexpr uint8_t kMaximumAcquisitionSamples = 21;
constexpr uint8_t kMaximumAcquisitionReadAttempts = 3;
constexpr uint32_t kAcquisitionReadRetryDelayMs = 50;
constexpr uint32_t kOfflineWriteRetryIntervalMs = 250;
constexpr uint32_t kOfflineAlertSampleIntervalMs = 500;
constexpr uint64_t kMinimumValidEpochMs = 1577836800000ULL;
constexpr uint32_t kRtcRefreshIntervalMs = 3600000;
constexpr uint32_t kRtcDiscoveryRetryIntervalMs = 10000;
constexpr uint64_t kRtcCorrectionThresholdMs = 2000ULL;
constexpr uint8_t kMaximumOfflineAlertRules = 24;
constexpr uint32_t kMinimumAutomaticShutdownSeconds = 60;
constexpr uint32_t kMaximumAutomaticShutdownSeconds = 86400;
constexpr uint32_t kDefaultAutomaticShutdownSeconds = 1800;
constexpr uint32_t kExternalCommandDebounceMs = 20;
constexpr uint32_t kExternalCommandLongPressMs = 2000;
constexpr uint32_t kExternalCommandMultiPressWindowMs = 400;
// Bit 62 distinguishes a session created autonomously by the sensor from the
// progressive session IDs assigned by Android, while remaining a positive
// signed 64-bit value throughout JSON, SQLite and the offline record format.
constexpr uint64_t kSensorOriginatedSessionMarker = 1ULL << 62;
constexpr uint64_t kSensorOriginatedSessionPayloadMask =
    kSensorOriginatedSessionMarker - 1ULL;

// ESP-IDF NVS keys may contain at most 15 characters. Keep the less obvious
// persisted names centralized so reads and writes cannot silently diverge.
constexpr char kPreferenceInternetPrimary[] = "inet_primary";
constexpr char kPreferenceAutoShutdownEnabled[] = "autooff_on";
constexpr char kPreferenceAutoShutdownSeconds[] = "autooff_secs";
constexpr char kPreferenceExternalCommandEnabled[] = "external_cmd";
static_assert(sizeof(kPreferenceInternetPrimary) - 1 <= 15,
              "NVS preference key is too long");
static_assert(sizeof(kPreferenceAutoShutdownEnabled) - 1 <= 15,
              "NVS preference key is too long");
static_assert(sizeof(kPreferenceAutoShutdownSeconds) - 1 <= 15,
              "NVS preference key is too long");
static_assert(sizeof(kPreferenceExternalCommandEnabled) - 1 <= 15,
              "NVS preference key is too long");

enum class Transport : uint8_t { None, Usb, Wifi, Bluetooth, Internet };
enum class WirelessMode : uint8_t { Off, Wifi, Bluetooth, Internet };
enum class ClockSource : uint8_t { Unavailable, Rtc, Phone };

struct UvirBandSample {
  float values[kUvirStoredBandCount] = {};
  bool saturated = false;
};

struct OfflineJob {
  bool enabled = false;
  bool externalCommand = false;
  uint64_t sessionId = 0;
  uint64_t nextAtMs = 0;
  uint32_t intervalSeconds = 60;
  uint64_t endAtMs = 0;
  uint32_t maximumCount = 0;
  uint32_t completedCount = 0;
  uint8_t samplesPerAcquisition = 1;
  uint32_t sampleSpacingMs = kDefaultStreamIntervalMs;
  bool discardExtremes = false;
  UvirConditionPlan condition;
  bool conditionStarted = true;
  uint64_t conditionDurationSeconds = 0;
  uint64_t startedAtMs = 0;
  uint64_t conditionFirstAllowedAtMs = 0;
  uint64_t conditionNextCheckAtMs = 0;
  bool conditionTriggered = false;
  bool conditionStopPending = false;
  bool conditionStartSignalPending = false;
  UvirBandSample conditionTriggerSample;
};

struct OfflineAlertRule {
  String metric;
  bool above = true;
  float threshold = 0.0f;
};

struct PersistentAlertRule {
  char metric[32] = {};
  uint8_t above = 1;
  float threshold = 0.0f;
};

struct PersistentRuntimeActivityStateV1 {
  uint32_t magic = 0x55565254;
  uint16_t version = 1;
  uint16_t size = 0;
  uint8_t automaticEnabled = 0;
  uint8_t externalCommand = 0;
  uint8_t conditionStarted = 1;
  uint8_t alertsEnabled = 0;
  uint64_t sessionId = 0;
  uint64_t nextAtMs = 0;
  uint32_t intervalSeconds = 60;
  uint64_t endAtMs = 0;
  uint32_t maximumCount = 0;
  uint32_t completedCount = 0;
  uint8_t samplesPerAcquisition = 1;
  uint32_t sampleSpacingMs = kDefaultStreamIntervalMs;
  uint8_t discardExtremes = 0;
  UvirConditionPlan condition;
  uint64_t conditionDurationSeconds = 0;
  uint64_t startedAtMs = 0;
  uint64_t conditionFirstAllowedAtMs = 0;
  uint64_t conditionNextCheckAtMs = 0;
  uint32_t alertRepeatSeconds = 30;
  uint64_t alertSessionId = 0;
  uint64_t nextAlertEvaluationMs = 0;
  uint8_t alertRuleCount = 0;
  PersistentAlertRule alertRules[kMaximumOfflineAlertRules];
};
struct PersistentRuntimeActivityState : PersistentRuntimeActivityStateV1 {
  PersistentRuntimeActivityState() { version = 2; }
  uint32_t alertStartDelaySeconds = 0;
  uint32_t alertDurationSeconds = 0;
  uint32_t alertMaximumRegistrations = 0;
  uint32_t alertCompletedRegistrations = 0;
  uint64_t alertStartAtMs = 0;
  uint64_t alertEndAtMs = 0;
};
static_assert(
    sizeof(PersistentRuntimeActivityState) <=
        UvirFram::kStateSlotBytes - 16,
    "Runtime activity state exceeds the FRAM journal slot");

enum class AveragedAcquisitionKind : uint8_t {
  None,
  Automatic,
  AutomaticCondition,
  OfflineAlert,
  ExternalManual,
};

struct AveragedAcquisitionState {
  AveragedAcquisitionKind kind = AveragedAcquisitionKind::None;
  UvirBandSample samples[kMaximumAcquisitionSamples];
  uint8_t targetCount = 0;
  uint8_t collectedCount = 0;
  uint8_t currentSampleAttempts = 0;
  uint32_t spacingMs = 0;
  uint32_t nextSampleAtMs = 0;
  uint64_t startedEpochMs = 0;
  bool discardExtremes = false;
};

UvirVisibleSensor visibleSensor;
UvirUvSensor uvSensor;
Preferences preferences;
uint64_t settingsUpdatedAtMs = 0;
bool applyingDatedSettings = false;
uint32_t settingsCommandErrors = 0;
bool settingsWirelessReconfigurePending = false;
WirelessMode settingsWirelessNextMode = WirelessMode::Off;
UvirOfflineStore offlineStore;
UvirFram fram;
UvirRtcClock rtcClock;
UvirStatusLed statusLed;
UvirStatusBuzzer statusBuzzer;
UvirDebugPerformancePlayer debugPerformance;
bool debugPerformanceCompletionPending = false;
Transport debugPerformanceTransport = Transport::None;
UvirDebugPerformanceKind debugPerformanceRunningKind =
    UvirDebugPerformanceKind::None;
BluetoothSerial bluetoothSerial;
std::atomic<bool> bluetoothPairingResetInProgress{false};
WiFiServer wifiServer(kWifiPort);
WiFiClient wifiClient;
UvirWifiOutput wifiOutput(wifiClient);
WiFiClientSecure internetClient;
MqttClient internetMqttClient(internetClient);
WiFiUDP wifiDiscovery;
bool streamEnabled = false;
bool appSessionActive = false;
bool wifiAuthenticated = false;
bool bluetoothAuthenticated = false;
bool internetAuthenticated = false;
bool internetRelayReady = false;
bool wifiServicesStarted = false;
uint32_t streamIntervalMs = kDefaultStreamIntervalMs;
uint32_t lastHostActivityMs = 0;
uint32_t nextSampleAtMs = 0;
uint32_t sequenceNumber = 0;
uint32_t lastWifiConnectionAttemptMs = 0;
uint32_t wifiClientConnectedAtMs = 0;
uint32_t lastInternetConnectionAttemptMs = 0;
uint32_t internetRelayReadyAtMs = 0;
uint32_t wirelessModeStartedAtMs = 0;
uint32_t lastBluetoothSignalRequestMs = 0;
Transport activeTransport = Transport::None;
WirelessMode wirelessMode = WirelessMode::Off;
bool wirelessFallbackActive = false;
bool wirelessFallbackSwitchNow = false;
bool wifiEnabled = true;
bool bluetoothEnabled = true;
String usbCommandBuffer;
String wifiCommandBuffer;
String bluetoothCommandBuffer;
String internetCommandBuffer;
String sensorDeviceId;
String authToken;
String wifiSsid;
String wifiPassword;
String wifiHostname;
bool internetEnabled = false;
bool internetUsePrimaryWifi = true;
String internetWifiSsid;
String internetWifiPassword;
String internetRelayHost;
uint16_t internetRelayPort = 8883;
String internetMqttUsername;
String internetMqttPassword;
String internetCommandTopic;
String internetEventTopic;

class UvirMqttOutput : public Print {
 public:
  size_t write(uint8_t value) override {
    if (value == '\n' || value == '\r') {
      publishLine();
      return 1;
    }
    if (line_.length() >= 16384) {
      line_ = "";
      return 0;
    }
    line_ += static_cast<char>(value);
    return 1;
  }

  size_t write(const uint8_t *buffer, size_t size) override {
    size_t written = 0;
    while (written < size && write(buffer[written]) == 1) {
      ++written;
    }
    return written;
  }

  void flush() override { publishLine(); }

 private:
  void publishLine() {
    if (line_.isEmpty()) return;
    if (!internetRelayReady || !internetMqttClient.connected() ||
        internetEventTopic.isEmpty()) {
      line_ = "";
      return;
    }
    const size_t length = line_.length();
    // ArduinoMqttClient waits synchronously for a QoS 1 PUBACK and polls the
    // same socket while waiting. Commands delivered in that interval can be
    // consumed before serviceInternet() reads their payload. Sensor events use
    // QoS 0 to keep this path non-blocking; offline records remain reliable
    // through Uvir's explicit SYNC_ACK/replay protocol.
    if (internetMqttClient.beginMessage(
            internetEventTopic, length, false, 0) == 1) {
      internetMqttClient.write(
          reinterpret_cast<const uint8_t *>(line_.c_str()), length);
      internetMqttClient.endMessage();
    }
    line_ = "";
  }

  String line_;
};

UvirMqttOutput internetOutput;
String bluetoothName;
String bluetoothPin;
esp_bd_addr_t bluetoothClientAddress = {};
volatile bool bluetoothClientAddressAvailable = false;
volatile bool bluetoothRssiDeltaAvailable = false;
volatile int8_t bluetoothRssiDelta = 0;
OfflineJob offlineJob;
OfflineAlertRule offlineAlertRules[kMaximumOfflineAlertRules];
uint8_t offlineAlertRuleCount = 0;
bool offlineAlertsEnabled = false;
uint32_t offlineAlertRepeatSeconds = 30;
bool offlineAlertRecordingEnabled = true;
uint64_t offlineAlertSessionId = 0;
uint32_t offlineAlertStartDelaySeconds = 0;
uint32_t offlineAlertDurationSeconds = 0;
uint32_t offlineAlertMaximumRegistrations = 0;
uint32_t offlineAlertCompletedRegistrations = 0;
uint64_t offlineAlertStartAtMs = 0;
uint64_t offlineAlertEndAtMs = 0;
bool alertConfigurationInProgress = false;
bool alertActivityBeforeConfiguration = false;
uint64_t nextOfflineAlertSampleAtMs = 0;
uint64_t epochBaseMs = 0;
uint32_t epochBaseUptimeMs = 0;
ClockSource clockSource = ClockSource::Unavailable;
uint32_t nextRtcRefreshAtMs = 0;
uint64_t lastRtcEpochMs = 0;
uint64_t lastOfflineRecordId = 0;
bool statusLedEnabled = true;
uint8_t statusLedBrightness = 10;
bool statusBuzzerEnabled = true;
uint8_t statusBuzzerVolume = 10;
bool autonomousRecordingAllowed = true;
bool automaticShutdownEnabled = false;
bool externalCommandEnabled = true;
uint32_t automaticShutdownSeconds = kDefaultAutomaticShutdownSeconds;
uint32_t automaticShutdownIdleStartedMs = 0;
bool offlineStorageError = false;
bool offlineStorageFull = false;
uint32_t syncAcquisitionCount = 0;
uint32_t syncAlertCount = 0;
uint32_t syncErrorCount = 0;
bool syncStorageWasFull = false;
uint64_t lastOfflineErrorAtMs = 0;
String lastOfflineErrorCode;
uint64_t nextAlertEvaluationEpochMs = 0;
uint8_t samplingSamplesPerResult = 5;
uint32_t samplingSpacingMs = kDefaultStreamIntervalMs;
bool samplingDiscardExtremes = true;
float visibleCalibrationFactor = 1.0f;
float uvCalibrationFactor = 1.0f;
UvirBandSample liveSampleWindow[kMaximumAcquisitionSamples];
uint8_t liveSampleWindowCount = 0;
uint8_t liveSampleWindowNext = 0;
UvirBandSample latestContinuousSample;
bool latestContinuousSampleAvailable = false;
uint32_t latestContinuousSampleAtMs = 0;
uint32_t nextContinuousSampleAtMs = 0;
bool pendingLiveAcquisition = false;
UvirStoredRecord pendingLiveAcquisitionRecord;
uint32_t pendingLiveAcquisitionSentAtMs = 0;
bool pendingOfflineAlert = false;
UvirStoredRecord pendingOfflineAlertRecord;
uint32_t pendingOfflineAlertRetryAtMs = 0;
AveragedAcquisitionState averagedAcquisition;
uint8_t externalAcquisitionRequestsPending = 0;
uint64_t externalAcquisitionQueuedSessionId = 0;
uint8_t externalCommandShortPressCount = 0;
uint32_t externalCommandLastShortPressMs = 0;
bool externalGestureAcquisitionProvisional = false;
bool externalCommandGesturePrimed = false;
portMUX_TYPE externalCommandMux = portMUX_INITIALIZER_UNLOCKED;
volatile bool externalCommandPressActive = false;
volatile bool externalCommandLongPressReported = false;
volatile uint8_t externalCommandShortPressPendingCount = 0;
volatile bool externalCommandLongPressPending = false;
volatile uint32_t externalCommandPressedAtUs = 0;
bool runtimeStatePersistenceEnabled = false;

void persistRuntimeActivityState();
bool restoreRuntimeActivityState();
void reconcileRestoredActivityState();

bool sensorOperationActive();
bool sensorActivityActive();
bool activityReported = false;
bool lastReportedActivity = false;
Transport lastActivityTransport = Transport::None;

String randomCredential(size_t length, const char *alphabet) {
  String value;
  value.reserve(length);
  const size_t alphabetLength = strlen(alphabet);
  for (size_t index = 0; index < length; ++index) {
    value += alphabet[esp_random() % alphabetLength];
  }
  return value;
}

void printUInt64(Print &output, uint64_t value) {
  char text[24];
  snprintf(text, sizeof(text), "%llu", static_cast<unsigned long long>(value));
  output.print(text);
}

uint64_t currentEpochMs() {
  if (epochBaseMs == 0) {
    return 0;
  }
  return epochBaseMs + static_cast<uint32_t>(millis() - epochBaseUptimeMs);
}

void anchorRuntimeClock(uint64_t epochMs) {
  epochBaseMs = epochMs;
  epochBaseUptimeMs = millis();
}

const __FlashStringHelper *clockSourceName() {
  switch (clockSource) {
    case ClockSource::Rtc:
      return F("rtc");
    case ClockSource::Phone:
      return F("phone");
    default:
      return F("unavailable");
  }
}

bool probeI2cAddress(uint8_t address) {
  Wire.beginTransmission(address);
  return Wire.endTransmission() == 0;
}

bool readAndApplyRtcClock(bool forceApply) {
  uint64_t rtcEpochMs = 0;
  if (!rtcClock.readEpochMs(rtcEpochMs) ||
      rtcEpochMs < kMinimumValidEpochMs) {
    return false;
  }
  lastRtcEpochMs = rtcEpochMs;
  const uint64_t runtimeEpochMs = currentEpochMs();
  const uint64_t difference =
      runtimeEpochMs > rtcEpochMs
          ? runtimeEpochMs - rtcEpochMs
          : rtcEpochMs - runtimeEpochMs;
  if (forceApply || runtimeEpochMs == 0 ||
      difference > kRtcCorrectionThresholdMs) {
    anchorRuntimeClock(rtcEpochMs);
    clockSource = ClockSource::Rtc;
  }
  return true;
}

void initializeRtcClock() {
  for (uint8_t attempt = 0; attempt < 5 && !rtcClock.available(); ++attempt) {
    rtcClock.begin(Wire, UvirHardware::kDs3231Address);
    if (!rtcClock.available()) delay(50);
  }
  const bool clockRestored =
      rtcClock.available() && readAndApplyRtcClock(true);
  nextRtcRefreshAtMs =
      millis() + (clockRestored
                      ? kRtcRefreshIntervalMs
                      : kRtcDiscoveryRetryIntervalMs);
}

void serviceRtcClock() {
  if (static_cast<int32_t>(millis() - nextRtcRefreshAtMs) < 0) {
    return;
  }
  if (!rtcClock.available()) {
    rtcClock.begin(Wire, UvirHardware::kDs3231Address);
  }
  const bool clockRestored =
      rtcClock.available() && readAndApplyRtcClock(currentEpochMs() == 0);
  if (clockRestored) {
    reconcileRestoredActivityState();
  }
  nextRtcRefreshAtMs =
      millis() + (clockRestored
                      ? kRtcRefreshIntervalMs
                      : kRtcDiscoveryRetryIntervalMs);
}

bool phoneIsAuthenticated() {
  return activeTransport == Transport::Usb ||
         (wifiAuthenticated && wifiClient && wifiClient.connected()) ||
         (bluetoothAuthenticated && bluetoothSerial.hasClient()) ||
         (internetAuthenticated && internetMqttClient.connected());
}

bool alertMonitoringActive() {
  return offlineAlertsEnabled && offlineAlertRuleCount > 0;
}

void setAutomaticJobEnabled(bool enabled, bool announceChange) {
  const bool wasEnabled = offlineJob.enabled;
  offlineJob.enabled = enabled;
  if (runtimeStatePersistenceEnabled) persistRuntimeActivityState();
  if (!announceChange || wasEnabled == enabled) return;
  if (enabled) {
    statusBuzzer.signalActivityStarted();
  } else {
    statusBuzzer.signalActivityStopped();
  }
}

void signalAlertActivityTransition(bool wasActive, bool isActive) {
  if (wasActive == isActive) return;
  if (isActive) {
    statusBuzzer.signalActivityStarted();
  } else {
    statusBuzzer.signalActivityStopped();
  }
}

String createDeviceId() {
  const uint64_t chipId = ESP.getEfuseMac();
  char value[13];
  snprintf(
      value,
      sizeof(value),
      "%04X%08lX",
      static_cast<uint16_t>(chipId >> 32),
      static_cast<unsigned long>(chipId));
  return String(value);
}

const char *wirelessModeName(WirelessMode mode) {
  switch (mode) {
    case WirelessMode::Wifi:
      return "wifi";
    case WirelessMode::Bluetooth:
      return "bluetooth";
    case WirelessMode::Internet:
      return "internet";
    default:
      return "off";
  }
}

const char *transportName(Transport transport) {
  switch (transport) {
    case Transport::Usb:
      return "usb";
    case Transport::Wifi:
      return "wifi";
    case Transport::Bluetooth:
      return "bluetooth";
    case Transport::Internet:
      return "internet";
    default:
      return "none";
  }
}
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
void loop() {
  // Physical automation must remain responsive even while a radio transport
  // is reconnecting or servicing network traffic.
  serviceExternalCommandInput();
  serviceRtcClock();
  serviceOfflineRecording();
  readCommands(Serial, Serial, usbCommandBuffer, Transport::Usb);
  serviceWifi();
  serviceInternet();
  serviceBluetooth();
  serviceBluetoothSignalStrength();
  serviceWirelessFallback();
  debugPerformance.update(statusLed, statusBuzzer);
  serviceDebugPerformanceCompletion();
  serviceAutomaticShutdown();

  const uint32_t now = millis();
  if (appSessionActive && now - lastHostActivityMs >= kHostTimeoutMs) {
    const Transport timedOutTransport = activeTransport;
    stopStreaming();
    // An unresponsive app may leave any wireless link looking physically
    // connected. Expire its authentication and restart the same fallback
    // cycle regardless of whether it used Wi-Fi, Bluetooth or Internet.
    if (timedOutTransport == Transport::Wifi) {
      wifiAuthenticated = false;
      wifiClient.stop();
    } else if (timedOutTransport == Transport::Bluetooth) {
      bluetoothAuthenticated = false;
      bluetoothSerial.disconnect();
    } else if (timedOutTransport == Transport::Internet) {
      internetAuthenticated = false;
    }
    if (timedOutTransport == Transport::Wifi ||
        timedOutTransport == Transport::Bluetooth ||
        timedOutTransport == Transport::Internet) {
      resumeWirelessFallbackAfterDisconnect();
    }
  }

  serviceContinuousSampling();

  if (streamEnabled && static_cast<int32_t>(now - nextSampleAtMs) >= 0) {
    Print *output = outputForTransport(activeTransport);
    if (output == nullptr) {
      stopStreaming();
    } else {
      printSample(*output);
      nextSampleAtMs = millis() + streamIntervalMs;
    }
  }

  const bool activeTransportReady =
      activeTransport != Transport::None &&
      outputForTransport(activeTransport) != nullptr &&
      isAuthenticated(activeTransport);
  const bool connectedToPhone = appSessionActive && activeTransportReady;
  const bool authenticatedWirelessStandby =
      !appSessionActive &&
      ((wifiAuthenticated && wifiClient && wifiClient.connected()) ||
       (bluetoothAuthenticated && bluetoothSerial.hasClient()) ||
       (internetAuthenticated && internetMqttClient.connected()));
  const bool appConnectionAttemptActive =
      (wifiClient && wifiClient.connected() && !wifiAuthenticated) ||
      (bluetoothSerial.hasClient() && !bluetoothAuthenticated);
  refreshSensorActivity();
  statusLed.setPendingSync(offlineStore.totalCount() > 0);
  if (connectedToPhone) {
    statusLed.setBaseState(UvirLedBaseState::Connected);
  } else if (authenticatedWirelessStandby) {
    // Android keeps this authenticated control channel available only to
    // switch away from an unavailable USB source. It is not a live session.
    statusLed.setBaseState(UvirLedBaseState::Disconnected);
  } else if (appConnectionAttemptActive) {
    statusLed.setBaseState(UvirLedBaseState::Connecting);
  } else {
    statusLed.setBaseState(UvirLedBaseState::Disconnected);
  }
  // Without a requesting app the AS7343 remains powered down and the loop yields.
  delay(appSessionActive ? 2 : 20);
}

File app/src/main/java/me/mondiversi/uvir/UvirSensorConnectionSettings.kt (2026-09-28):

package me.mondiversi.uvir

import android.content.Context
import android.content.Intent
import android.provider.Settings
import androidx.compose.foundation.layout.fillMaxWidth
import androidx.compose.foundation.layout.size
import androidx.compose.material3.OutlinedButton
import androidx.compose.material3.OutlinedTextField
import androidx.compose.material3.Text
import androidx.compose.runtime.Composable
import androidx.compose.ui.Modifier
import androidx.compose.ui.graphics.Color
import androidx.compose.ui.res.stringResource
import androidx.compose.ui.unit.dp
import androidx.compose.ui.unit.sp

@Composable
internal fun UvirSensorConnectionSettings(
    context: Context,
    sensorCredentials: UvirSensorCredentials,
    sensorConnectionSectionExpanded: Boolean,
    onSensorConnectionSectionExpandedChange: (Boolean) -> Unit,
    sensorSettingsEnabled: Boolean,
    sensorWifiRadioEnabled: Boolean,
    onSensorWifiRadioEnabledChange: (Boolean) -> Unit,
    onRequestCurrentWifiSsid: () -> Unit,
    sensorBluetoothRadioEnabled: Boolean,
    onSensorBluetoothRadioEnabledChange: (Boolean) -> Unit,
    sensorWifiSsid: String,
    onSensorWifiSsidChange: (String) -> Unit,
    sensorWifiPassword: String,
    onSensorWifiPasswordChange: (String) -> Unit,
    sensorInternetEnabled: Boolean,
    onSensorInternetEnabledChange: (Boolean) -> Unit,
    sensorInternetUsePrimaryWifi: Boolean,
    onSensorInternetUsePrimaryWifiChange: (Boolean) -> Unit,
    sensorInternetWifiSsid: String,
    onSensorInternetWifiSsidChange: (String) -> Unit,
    sensorInternetWifiPassword: String,
    onSensorInternetWifiPasswordChange: (String) -> Unit,
    sensorInternetRelayHost: String,
    onSensorInternetRelayHostChange: (String) -> Unit,
    sensorInternetRelayPort: String,
    onSensorInternetRelayPortChange: (String) -> Unit,
    sensorInternetMqttUsername: String,
    onSensorInternetMqttUsernameChange: (String) -> Unit,
    sensorInternetMqttPassword: String,
    onSensorInternetMqttPasswordChange: (String) -> Unit,
    onSensorConnectionModeChanged: (SensorConnectionMode) -> Unit,
    cardColor: Color,
    primaryText: Color,
    secondaryText: Color
) {
    val radioCommit = LocalSettingsCommit.current
    val wirelessControlsEnabled =
        sensorSettingsEnabled && sensorCredentials.isProvisioned

    SettingsSection(
        settingsPage = UvirSettingsPage.SENSOR_CONNECTION,
        title = stringResource(R.string.settings_section_sensor_connection),
        titleIcon = ConnectivityIconType.SENSOR_CONNECTION,
        expanded = sensorConnectionSectionExpanded,
        enabled = true,
        dimContentWhenDisabled = false,
        onExpandedChange = { expanded ->
            onSensorConnectionSectionExpandedChange(expanded)
            saveSettingsSectionExpanded(
                context,
                KEY_SETTINGS_SENSOR_CONNECTION_EXPANDED,
                expanded
            )
        },
        containerColor = cardColor,
        titleColor = primaryText,
        chevronColor = secondaryText,
        dividerColor = secondaryText.copy(alpha = 0.28f),
        contentSpacing = UvirIslandSpacing,
        wrapDetailContent = false
    ) {
        SettingsSection(
            title = stringResource(R.string.sensor_connection_usb),
            titleIcon = ConnectivityIconType.USB,
            expanded = true,
            enabled = true,
            onExpandedChange = null,
            highlightExpandedHeader = false,
            showExpandedDivider = true,
            containerColor = cardColor,
            titleColor = primaryText,
            chevronColor = secondaryText,
            dividerColor = secondaryText.copy(alpha = 0.28f),
            contentSpacing = UvirSettingsControlGap
        ) {
            SettingsPageDescription(
                text = stringResource(R.string.sensor_usb_priority_description),
                color = secondaryText
            )

            SettingsPageDescription(
                text = stringResource(R.string.sensor_connection_provisioning_reminder),
                color = secondaryText
            )

            SettingsPageDescription(
                text = stringResource(R.string.sensor_connection_configuration_paths_description),
                color = secondaryText
            )
        }
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

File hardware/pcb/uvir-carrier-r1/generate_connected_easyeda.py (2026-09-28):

"""Generate a visibly wired EasyEDA Standard schematic for the Uvir carrier.

The ESP32 header labels follow the user's USB-down 38-pin reference photo.
This is an electrical schematic, not an assigned-footprint PCB layout.
"""

from __future__ import annotations

from collections import defaultdict, deque
import json
from pathlib import Path
import re


HERE = Path(__file__).resolve().parent
SOURCE = HERE / "uvir-carrier-r1-pin-netlist.json"
OUTPUT = HERE / "uvir-carrier-r1-easyeda-standard-schematic.json"
FIRMWARE_PINS = HERE.parents[2] / "firmware/esp32/UvirSensor/UvirHardwareConfig.h"
GRID = 5


def main() -> None:
    source = json.loads(SOURCE.read_text(encoding="utf-8"))
    firmware = FIRMWARE_PINS.read_text(encoding="utf-8")
    gpio_constants = {
        "kI2cSdaPin": 21, "kI2cSclPin": 22,
        "kSdChipSelectPin": 13, "kSdClockPin": 18,
        "kSdMisoPin": 19, "kSdMosiPin": 23,
        "kStatusLedRedPin": 25, "kStatusLedGreenPin": 26,
        "kOperationLedBluePin": 27, "kStatusBuzzerPin": 32,
        "kExternalCommandPin": 33,
    }
    for name, pin in gpio_constants.items():
        if re.search(rf"\b{name}\s*=\s*{pin}\s*;", firmware) is None:
            raise ValueError(f"Schematic GPIO differs from firmware: {name} != {pin}")
    connection_nets = {
        connection: net["name"]
        for net in source["nets"]
        for connection in net["connections"]
    }
    if len(connection_nets) != sum(len(net["connections"]) for net in source["nets"]):
        raise ValueError("A component pin belongs to more than one net")
    expected_nets = {net["name"]: set(net["connections"]) for net in source["nets"]}
    serial = 0

    def gid() -> str:
        nonlocal serial
        serial += 1
        return f"ggeuvir{serial:05d}"

    shapes: list[str] = []
    pin_points: dict[str, tuple[int, int]] = {}
    segments: dict[str, list[tuple[tuple[int, int], tuple[int, int]]]] = defaultdict(list)
    junctions: list[tuple[str, tuple[int, int]]] = []

    def text(x: int, y: int, value: str, *, size: int = 10, bold: bool = False) -> None:
        shapes.append(
            f"T~L~{x}~{y}~0~#000080~Arial~{size}pt~"
            f"{'bold' if bold else 'normal'}~normal~~comment~{value}~1~start~{gid()}~0"
        )

    def symbol(
        ref: str, name: str, x: int, y: int, width: int,
        left: list[tuple[str, str, str]], right: list[tuple[str, str, str]],
    ) -> None:
        height = 28 + 25 * max(len(left), len(right))
        # Package intentionally blank until the real socket dimensions are measured.
        parts = [
            f"LIB~{x}~{y}~package``nameAlias`Value`Value`{name}`spicePre`{ref[0]}`"
            f"~0~0~{gid()}",
            f"T~P~{x}~{y - 17}~0~#000080~Arial~~~~~comment~{ref}~1~start~{gid()}~0",
            f"T~N~{x + 35}~{y - 17}~0~#000080~Arial~~~~~comment~{name}~1~start~{gid()}~0",
            f"R~{x}~{y}~0~0~{width}~{height}~#A00000~1~0~none~{gid()}~0",
        ]
        for side, pins in (("left", left), ("right", right)):
            for index, (connection, label, number) in enumerate(pins):
                if connection not in connection_nets or connection in pin_points:
                    raise ValueError(f"Missing or duplicate connection: {connection}")
                py = y + 30 + 25 * index
                if side == "left":
                    dot_x, body_x, rotation, anchor = x - 20, x, 180, "start"
                    path = f"M {dot_x} {py} h 20"
                    name_x, number_x = x + 5, x - 15
                else:
                    dot_x, body_x, rotation, anchor = x + width + 20, x + width, 0, "end"
                    path = f"M {dot_x} {py} h -20"
                    name_x, number_x = x + width - 5, x + width + 15
                pin_points[connection] = (dot_x, py)
                parts.append(
                    f"P~show~0~{number}~{dot_x}~{py}~{rotation}~{gid()}~0"
                    f"^^{dot_x}~{py}"
                    f"^^{path}~#880000"
                    f"^^1~{name_x}~{py + 3}~0~{label}~{anchor}~~7pt"
                    f"^^0~{number_x}~{py - 4}~0~{number}~{anchor}~~7pt"
                    f"^^0~{body_x}~{py}"
                    f"^^0~M {body_x} {py - 3} L {body_x} {py + 3}"
                )
        shapes.append("#@$".join(parts))

    def point(connection: str) -> tuple[int, int]:
        return pin_points[connection]

    def wire(net: str, *points: tuple[int, int]) -> None:
        for a, b in zip(points, points[1:]):
            if a == b:
                continue
            if a[0] != b[0] and a[1] != b[1]:
                raise ValueError(f"Non-orthogonal wire {net}: {a} -> {b}")
            if any(coord % GRID for p in (a, b) for coord in p):
                raise ValueError(f"Off-grid wire {net}: {a} -> {b}")
            segments[net].append((a, b))
            shapes.append(f"W~{a[0]} {a[1]} {b[0]} {b[1]}~#008800~2~0~none~{gid()}~0")

    def junction(net: str, p: tuple[int, int]) -> None:
        junctions.append((net, p))
        shapes.append(f"J~{p[0]}~{p[1]}~2.5~#CC0000~{gid()}~0")

    def net_label(net: str, p: tuple[int, int]) -> None:
        # These labels supplement visible continuous wires; they do not replace them.
        shapes.append(
            f"N~{p[0]}~{p[1]}~0~#000080~{net}~{gid()}~start~"
            f"{p[0] + 5}~{p[1] - 5}~Arial~8pt~0"
        )

    text(55, 55, "UVIR CARRIER R1 - CONNECTED ELECTRICAL SCHEMATIC", size=14, bold=True)
    text(55, 78, "ESP32 header labels J2/J3 correspond to the USB-down 38-pin reference.", size=9)
    text(55, 96, "Green lines are continuous wires; red dots are intentional branch junctions.", size=9)
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

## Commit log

2026-09-01 Remove discontinued desktop prototype from repository
2026-09-15 Release Uvir 1.1.0 sensor platform overhaul
    [partitions.csv, uvir-carrier-r0-board-outline.dxf, uvir-carrier-r0-bom.csv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]
2026-09-18 Expand sensor workflows, exports, and diagnostics
    [uvir-carrier-r0-pin-map.csv]
2026-09-18 Harden Android device verification
2026-10-17 Publish current UVIR development snapshot and hardware setup guide
    Consolidate multisensor UI, localization, exports, update recovery and portable signing configuration. Include sensor feedback and gain refinements with host tests. Add anonymized EasyEDA layouts, sc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
2026-10-17 Complete hardware wiring and standalone sensor integration guides
2026-10-22 Document directional sensor tubes and diffuser requirements
2026-10-22 Release Uvir 1.4.0 with channel calibration, SI storage and precise exports
2026-10-27 Prepare USB-only phone-owned sensor architecture and preserve ESP32 legacy
2026-10-28 Document retired ESP32 releases and preserved legacy source
2026-11-01 Release Uvir 0.1.1 and document suspended optical calibration
2026-11-01 Keep only the current FT232H hardware in main
